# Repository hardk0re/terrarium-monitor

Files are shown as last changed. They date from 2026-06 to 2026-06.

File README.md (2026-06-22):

# 🦎 Terrarium Monitor

A Raspberry Pi-based enclosure monitoring and automation system, built for my daughter's Crested Gecko. Yes, it's total overkill. But it works great.

---

## The Story

I looked at a dozen of these projects online and they were all either too complicated, half-finished, or required cloud accounts and subscriptions. I just wanted something that would:

- Show me temperature and humidity at a glance
- Turn the lights on and off on a schedule
- Kick on the mister if it gets too dry
- Run a fan if it gets too hot
- Let me check in on the enclosure remotely
- Keep a log of feedings and care

So I built it myself. It runs entirely on the local network — no cloud, no subscriptions, no accounts required (except an optional free OpenWeatherMap API key for outdoor weather).

---

## Features

- **Dual SHT31-D sensor monitoring** — temperature and humidity from up to N sensors (expandable via config), with optional per-sensor calibration offsets for chip-to-chip variance
- **ST7789 2" display** — sensor data by default; pre-empts to a gecko-mood page when the gecko isn't happy, and flashes a confirmation screen when a physical button is pressed
- **Day/night display brightness** — PWM-controlled backlight with a separate `night_brightness` and configurable `night_start` / `night_end` window
- **Colour-coded readings** — green = good range, blue = too cold/dry, red = too hot/humid, yellow = sensor error
- **Misting control** — 5V relay triggers automatically when humidity drops below threshold, with configurable runtime, cooldown delay, and 24-hour run cap
- **Fan control** — separate 5V relay for high/low temperature, same configurable runtime and cooldown system; threshold unit (`F`/`C`) follows the display unit or can be set per section
- **TAPO/KASA smart plug lighting** — local API control, no cloud required, fully scheduled (on/off time per plug); shutdown leaves plugs in whatever state they were in
- **TAPO camera** — ONVIF snapshot every 30 seconds, live image in web dashboard, optional timelapse viewer with scrub bar + playback controls and configurable retention
- **Outdoor weather** — OpenWeatherMap integration with current conditions card, 24h history chart, and feels-like / wind
- **Gecko mood widget** — color-changing gecko (green/yellow/red) on the dashboard derived from temperature, humidity, and check-in recency; tunable thresholds in `[gecko]`. Mood transitions are logged and Pushover-notified.
- **Pushover notifications** — per-category toggles (startup/shutdown/care/feeding/relay/error/etc.), louder sounds for errors and upset-gecko transitions, plus a one-click **Test Pushover** button on the config page
- **Care / feeding check-in reminder** — dashboard banner + Pushover when no care or feeding log has been recorded in `care_reminder_hours`
- **Sensor failure alerts** — if a sensor goes silent for `sensor_failure_alert_minutes`, an `error` event is raised (and Pushover-notified)
- **24h sensor averages widget** — average temp + half-moon humidity gauge per sensor, colour-banded with the same thresholds as the OLED
- **System stats widget** — CPU temperature, CPU %, RAM %, free disk, and uptime, with colour thresholds
- **Web dashboard** — live sensor data, charts, relay overrides, light controls, camera snapshot, feeding/care log, config editor
- **Event log viewer** — `/logs` page with category pills (care, feeding, gecko, relay, error, …), time-range filter, and full-text search
- **Feeding log** — one-tap buttons for configurable food items (crickets, waxworms, paste, etc.)
- **Care log** — one-tap buttons for configurable care activities (cleaning, misting, substrate change, vet visit, etc.)
- **Physical buttons** — up to three optional momentary push-buttons wired to GPIO pins, each with its own configurable log category (`care`, `feeding`, etc.) and message — handy when your hands are wet from misting and the web UI isn't convenient (one press → one log entry → display flash → Pushover if that category is enabled)
- **SQLite logging** — all sensor readings, weather, relay events, and care/feeding entries stored locally with configurable retention (default 31 days); web buttons to clear sensor data or the event log
- **Config editor** — edit any config value from the web UI without touching the Pi, plus a **Restart** button that asks systemd to bounce the service
- **Config reload** — most changes apply immediately without a restart
- **Systemd service** — auto-starts on boot, restarts on crash

---

## Hardware

| Component | Notes |
|---|---|
| Raspberry Pi 3B+ or better | CM4 with eMMC recommended for permanent installs |
| Waveshare 2" ST7789 IPS LCD | 240×320, SPI interface |
| SHT31-D sensor module(s) | I²C, supports multiple (0x44 / 0x45) |
| 5V relay module(s) | Active-LOW, for mister and fan |
| TP-Link Tapo smart plugs | P100/P105/P110, local API, no auth required |
| TP-Link Tapo camera | ONVIF enabled, local network |
| MicroSD card | High-endurance recommended (Samsung or SanDisk) |

---

## Wiring
Usefull RPI3 Pin-Out:


### SHT31-D Sensors (I²C)
```
Sensor 1 (0x44) → ADDR pin to GND or OPEN
Sensor 2 (0x45) → ADDR pin to 3.3V

Both sensors:
  VCC → Pin 1  (3.3V)
  GND → Pin 6  (GND)
  SDA → Pin 3  (GPIO2)
  SCL → Pin 5  (GPIO3)
```

### Relay – Mister (HOME ASSISTANT)
Intial plans for the mister was to use a 5V relay, however with so many WIFI enabled misters on ALIExpress, Home Assistant integration was simpler.  I could not get TUYA integration to work reliably.  If your running this your likely using HOMEASSISTANT, if not you should consider it. 

### Relay – Fan (GPIO 27)
```
IN  → Pin 13 (GPIO27)
VCC → Pin 4  (5V)
GND → Pin 14 (GND)
```

### Care/Feeding Buttons (up to 3, optional)
Momentary push-buttons. The internal pull-up keeps each line HIGH; pressing
shorts it to GND. No external resistors needed. Each button is independent —
enable only the ones you've wired in `config.ini` under `[care_button_1]`,
`[care_button_2]`, `[care_button_3]`.

These default pins are deliberately on the bottom-right corner of the header
so they don't collide with the display (which uses GPIO 24/25) and share a
single nearby GND:

```
Button 1: GPIO13  (Pin 33) ─┐
Button 2: GPIO19  (Pin 35) ─┼──── other leg → GND on Pin 39
Button 3: GPIO26  (Pin 37) ─┘
```

Each button section sets its own `category` (e.g. `care`, `feeding`) and
`message` (e.g. `Cleaning`, `Cricket`) — when pressed, that text is logged
under that category, shows up in the event log, and fires a Pushover
notification if `notify_<category>` is enabled in `[pushover]`.

### Waveshare 2" ST7789 Display
```
VCC → Pin 17 (3.3V)
GND → Pin 20 (GND)
DIN → Pin 19 (GPIO10 / MOSI)
CLK → Pin 23 (GPIO11 / SCLK)
CS  → Pin 24 (GPIO8  / CE0)
DC  → Pin 18 (GPIO24)
RST → Pin 22 (GPIO25)
BL  → Pin 12 (GPIO18 / PWM0)
```

---

## Software Setup

### 1. Enable interfaces
```bash
sudo raspi-config
# Interface Options → I2C → Enable
# Interface Options → SPI → Enable
sudo reboot
```

### 2. Copy project files
```bash
mkdir -p /home/pi/terrarium
cd /home/pi/terrarium
# copy all project files here
mkdir -p data
```

### 3. Create virtual environment and install dependencies
```bash
python3 -m venv venv
source venv/bin/activate

pip install \
  adafruit-blinka \
  adafruit-circuitpython-sht31d \
  RPi.GPIO \
  spidev \
  Pillow \
  flask \
  PyP100 \
  requests \
  opencv-python-headless
```

### 4. Configure
```bash
cp sample_config.ini config.ini
vi config.ini
```

Key things to set:
- `[tapo_plug_1]` / `[tapo_plug_2]` → IP addresses of your smart plugs
- `[camera]` → IP, ONVIF port, username, password
- `[weather]` → your OpenWeatherMap API key, latitude, longitude
- `[display]` → `temp_unit = F` or `C`
- `[mister]` / `[fan]` → thresholds and runtimes for your setup
- `[web]` → `site_title`, auth settings

### 5. Test run
```bash
source venv/bin/activate
python main.py
```

Open `http://<pi-ip>:8080` in your browser.

### 6. Install as a systemd service
```bash
sudo cp terrarium.service /etc/systemd/system/
sudo systemctl daemon-reload
sudo systemctl enable terrarium
sudo systemctl start terrarium

# Check logs
sudo journalctl -u terrarium -f
```

---

## File Structure

```
terrarium/
├── config.ini                  ← all settings
├── main.py                     ← entry point
├── sensor_manager.py           ← SHT31 sensor reading
├── data_logger.py              ← SQLite storage
├── relay_controller.py         ← GPIO relay control
├── tapo_controller.py          ← smart plug control
├── display_manager.py          ← ST7789 display driver
├── camera_manager.py           ← TAPO ONVIF camera
├── weather_manager.py          ← OpenWeatherMap
├── web_dashboard.py            ← Flask web UI
├── care_button.py              ← GPIO push-buttons (up to 3) → log entries
├── gecko_mood.py               ← shared mood scoring (dashboard + OLED)
├── pushover_notifier.py        ← Pushover push notifications
├── terrarium.service           ← systemd unit
└── stls/
    ├── LCD-CASE.stl            ← Front of LCD Case
    ├── LCD-REARCOVER.stl       ← Rear Cover
    ├── LCD-RETENTION.stl       ← Retention bar for LCD
    ├── LCD-ButtonRetention.stl ← Retention plates for standard project buttons
    ├── SHT31_BOTTOM.stl        ← SHT31 Case - Bottom
    ├── SHT31_TOP.stl           ← SHT31 Case - Top
└── data/
    ├── terrarium.db        ← SQLite database (auto-created)
    ├── terrarium.log       ← log file (auto-created)
    ├── snapshot.jpg        ← latest camera snapshot
    └── timelapse/          ← timelapse frames (if enabled)
```

---

## Web Dashboard

| URL | Description |
|-----|---|
| `http://<pi-ip>:8080/` | Live dashboard |
| `http://<pi-ip>:8080/logs` | Filterable event log viewer |
| `http://<pi-ip>:8080/timelapse` | Timelapse viewer with playback / scrubber |
| `http://<pi-ip>:8080/config` | Config editor (password protected) |
| `http://<pi-ip>:8080/api/status` | JSON status snapshot |
| `http://<pi-ip>:8080/api/history?hours=24` | Sensor history |
| `http://<pi-ip>:8080/api/sensors/averages?hours=24` | Per-sensor 24h averages |
| `http://<pi-ip>:8080/api/weather/history` | Weather history |
| `http://<pi-ip>:8080/api/gecko/status` | Current gecko mood + per-factor reasons |
| `http://<pi-ip>:8080/api/care/status` | Whether a care/feeding check-in is overdue |
| `http://<pi-ip>:8080/api/system/stats` | CPU temp / CPU % / RAM / free disk / uptime |
| `http://<pi-ip>:8080/api/logs?hours=24&categories=care,feeding&q=cricket` | Filtered event log |
| `POST /api/relay/Mister/on` | Force mister on |
| `POST /api/relay/Fan/off` | Force fan off |
| `POST /api/light/UVB%20Light/on` | Force plug on |
| `POST /api/pushover/test` | Send a test Pushover notification |
| `POST /api/sensors/clear` | Wipe all indoor sensor history |
| `POST /api/log/clear` | Wipe the event + relay log |

---

## Control Logic

```
Every poll_interval_seconds (default 30s):

  MISTER:
    if avg_humidity < humidity_threshold_low
    AND not running AND not in cooldown
    AND 24h run count < mister_max_runs_per_24h:
      → ON for mister_runtime_minutes
      → cooldown for mister_monitor_delay_minutes
      → re-evaluate

  FAN:
    if avg_temp > temp_threshold_high  (too hot)
    OR avg_temp < temp_threshold_low   (too cold)
    AND not running AND not in cooldown
    AND 24h run count < fan_max_runs_per_24h:
      → ON for fan_runtime_minutes
      → cooldown for fan_monitor_delay_minutes
      → re-evaluate

  LIGHTS:
    Background thread checks every 60s:
    if current time between on_time and off_time → ON
    else → OFF
```

---

## Adding More Sensors

Add a new `[sensor_N]` section to `config.ini` — no code changes needed:

```ini
[sensor_3]
enabled = true
name = Basking Spot
i2c_address = 0x44
i2c_bus = 3
```

> **Note:** Only two I²C addresses are available on a single bus (0x44 and 0x45). For more than two sensors on the same bus, use a TCA9548A I²C multiplexer.

## Security

> ⚠️ **Do not expose this dashboard directly to the public internet.** It's
> designed for use on a trusted LAN only. The dashboard is wide open by
> default, multiple destructive endpoints (`/api/relay/*`, `/api/shutdown`,
> `/api/sensors/clear`, `/api/log/clear`, the config editor) require no auth
> unless you flip `auth_enabled = true`, and there's no CSRF protection or
> HTTPS in front of Flask.

**Use it on your home LAN.** That's the whole threat model the project was
built for. Family members poking buttons is fine — exposing port 8080 on
your router is not.

**If you genuinely need to reach it while away from home**, use a VPN

**Even on your LAN**, a few cheap hardening steps are worth doing:

1. Set `auth_enabled = true` in `[web]` and change the default `password = terrarium`.
2. Change `app.secret_key` in `web_dashboard.py` to a random value
   (`python3 -c "import secrets; print(secrets.token_hex(32))"`). Without
   this, anyone who has seen the public repo can forge a logged-in session
   cookie.
3. Treat **anything you've ever put in `config.ini` while it was in a public
   git repo as compromised** — rotate camera, Pushover, OpenWeather, and any
   smart-plug credentials that have been pushed publicly.
4. Add a `.gitignore` for `config.ini` and `data/` so secrets and your
   sensor history don't end up in commits going forward.

## Notes

- The TAPO camera requires ONVIF to be enabled in the Tapo app under **Advanced Settings → ONVIF**
- Smart plugs on newer firmware may reject unauthenticated local control by default. In the Kasa app, open each device → **Advanced Settings → Third-party compatibility** (sometimes called *Allow third party control*) and enable it. With that toggle on, `PyP100`'s empty-credential path works again on the LAN.
- The web config editor saves immediately but some changes (GPIO pins, I²C addresses, web port) require a restart to take effect
- All data is stored locally in SQLite — nothing leaves your network
- Timelapse frames accumulate quickly; set `timelapse_retention_days` and `timelapse_interval_seconds` appropriately

## Restrospec
- I am not using features I thought I needed (currently).  Such as Mister or Fan, as a result I have disconnected the relay's as they were not required.  Leaving it here as it is an option.
- I am not entirely happy with the LCD enclosure, and sensor enclosures.  But they work.  I used Crazy Glue to hold parts in place such as buttons and the sensor top/bottom.
- External weather is something I thought interesting to log, not sure yet how much I will value this data.
- Originally all my sensors , LCD are connected with project pins/wires.  I found that USB-C connectors are cheap, support up to 16 pins, so I am going to build a new setup with USB-C connectors (confusing for some but this way if you need longer cables...just buy a new USB-C cable)

---

*Built with way too much enthusiasm for a gecko that probably doesn't care.*

LCD Screen:



Main Website:




Configuration Editor:


TimeLapse:


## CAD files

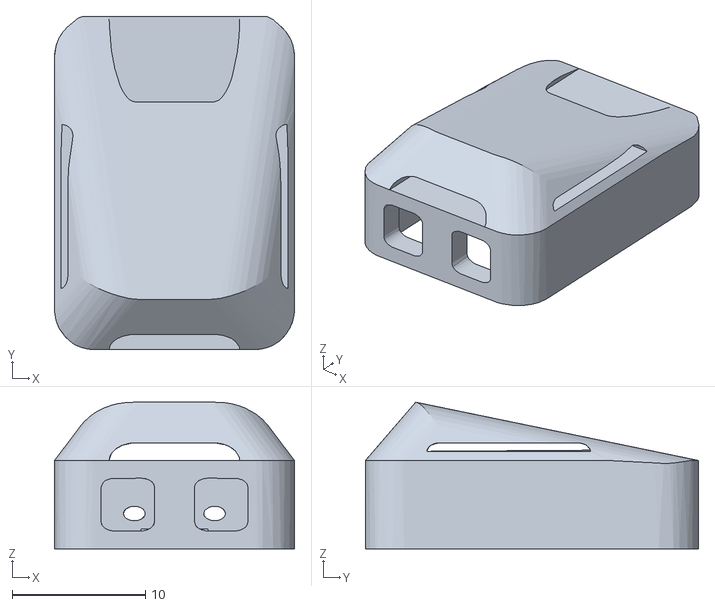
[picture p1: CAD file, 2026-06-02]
STLS/SHT31_TOP.stl
18.0 x 25.0 x 11.0

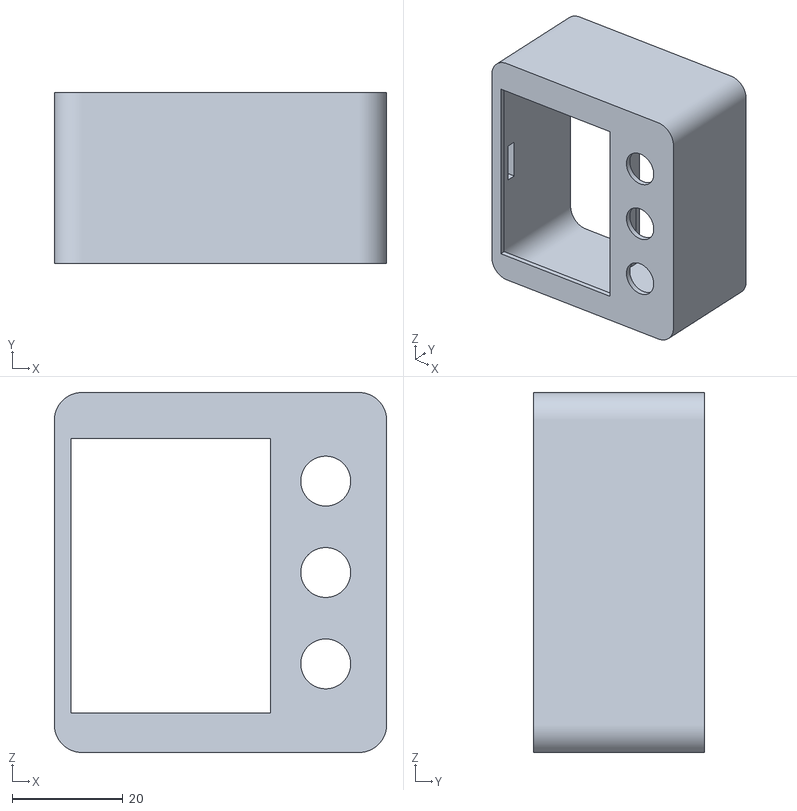
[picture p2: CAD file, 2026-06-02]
STLS/LCD-CASE.stl
60.0 x 30.8 x 65.0

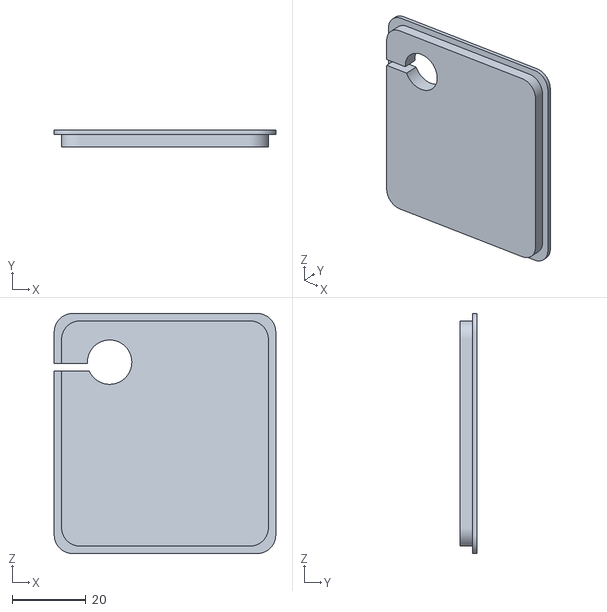
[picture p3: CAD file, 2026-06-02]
STLS/LCD-RETENTION.stl
60.0 x 4.60 x 65.0

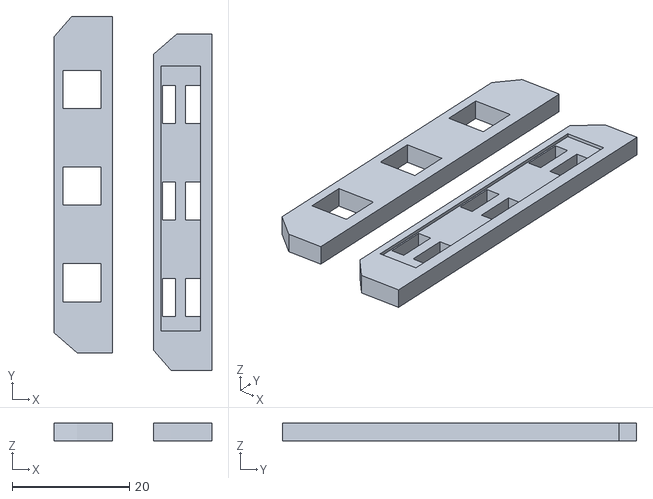
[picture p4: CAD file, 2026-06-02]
STLS/LCD-ButtonRetention.stl
27.0 x 60.5 x 3.00

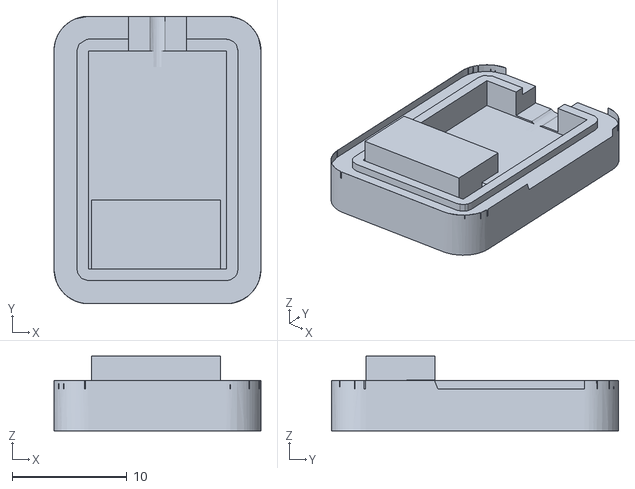
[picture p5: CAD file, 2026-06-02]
STLS/SHT31_BOTTOM.stl
18.0 x 25.0 x 6.50

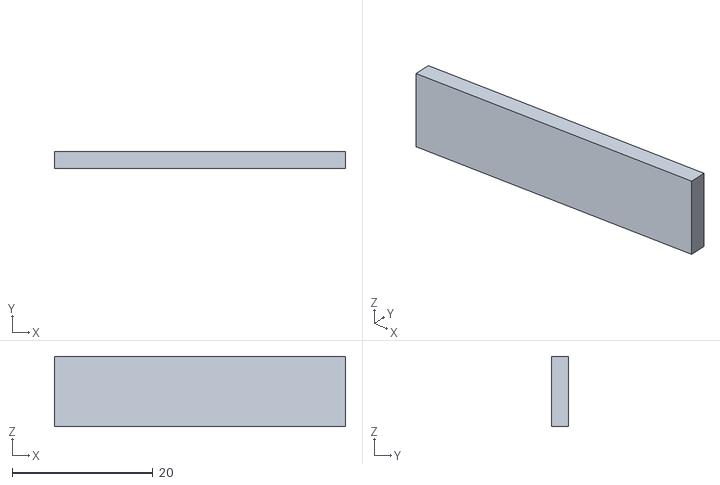
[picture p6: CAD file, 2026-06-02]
STLS/LCD-REARCOVER.stl
41.4 x 2.37 x 10.0

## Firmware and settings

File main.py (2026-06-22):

"""
main.py  –  Terrarium Monitor entry point
Run with:  python main.py
Or via systemd service (see terrarium.service)
"""

import time
import signal
import logging
import configparser
import threading
from pathlib import Path

# ── project modules ───────────────────────────────────────────────────
from sensor_manager   import SensorManager
from data_logger      import DataLogger
from relay_controller import build_mister, build_fan, cleanup_gpio
from homeassistant    import HomeAssistantClient
from tapo_controller  import LightingController
from display_manager  import DisplayManager
from camera_manager   import CameraManager
from weather_manager  import WeatherManager
from pushover_notifier import PushoverNotifier
from care_button       import CareButton
from gecko_mood        import compute_mood
import web_dashboard

# ── logging setup ─────────────────────────────────────────────────────
logging.basicConfig(
    level=logging.INFO,
    format="%(asctime)s [%(levelname)s] %(name)s: %(message)s",
    handlers=[
        logging.StreamHandler(),
        logging.FileHandler(Path(__file__).parent / "data" / "terrarium.log"),
    ]
)
logger = logging.getLogger("main")

# ── config ────────────────────────────────────────────────────────────
CONFIG_PATH = Path(__file__).parent / "config.ini"


def load_config() -> configparser.ConfigParser:
    cfg = configparser.ConfigParser()
    cfg.read(CONFIG_PATH)
    return cfg


# ── subsystem helpers ─────────────────────────────────────────────────

def build_subsystems(cfg: configparser.ConfigParser) -> dict:
    """Instantiate all controllable subsystems from config."""
    ha = HomeAssistantClient(
        cfg.get("general", "ha_base_url", fallback=""),
        cfg.get("general", "ha_token",    fallback=""),
    )
    dl       = DataLogger(cfg)
    sensors  = SensorManager(cfg)
    mister   = build_mister(cfg, dl, ha_client=ha)
    fan      = build_fan(cfg, dl)
    lighting = LightingController(cfg, data_logger=dl)
    camera   = CameraManager(cfg)
    weather  = WeatherManager(cfg, data_logger=dl)
    return dict(dl=dl, ha=ha, sensors=sensors, mister=mister,
                fan=fan, lighting=lighting, camera=camera, weather=weather)


def reload_subsystems(current: dict, cfg: configparser.ConfigParser) -> dict:
    """Gracefully stop current subsystems and rebuild from updated config."""
    logger.info("Reloading subsystems from updated config...")

    # Preserve last weather reading so display doesn't go blank
    last_weather = None
    if current.get("weather") and current["weather"].enabled:
        last_weather = current["weather"].latest()

    try:
        current["lighting"].stop()
        current["camera"].stop()
        current["weather"].stop()
        if current["mister"]: current["mister"].force_off()
        if current["fan"]:    current["fan"].force_off()
    except Exception as e:
        logger.warning("Error stopping subsystems during reload: %s", e)

    new = build_subsystems(cfg)
    new["lighting"].start_schedule_loop()
    new["camera"].start()
    new["weather"].start()

    # Restore last reading so display keeps showing weather immediately
    if last_weather and new["weather"].enabled:
        with new["weather"]._lock:
            new["weather"]._latest = last_weather

    return new


# ── logging helpers ───────────────────────────────────────────────────

def _apply_log_level(cfg: configparser.ConfigParser):
    """Read [general].log_level and apply it to the root logger.
    Werkzeug stays at INFO no matter what — its DEBUG mode is mostly
    HTTP-handshake noise that isn't useful when chasing a terrarium issue."""
    level_str = cfg.get("general", "log_level", fallback="INFO").strip().upper()
    level = getattr(logging, level_str, None)
    if not isinstance(level, int):
        logger.warning("Unknown log_level %r, falling back to INFO.", level_str)
        level = logging.INFO
    logging.getLogger().setLevel(level)
    logging.getLogger("werkzeug").setLevel(logging.INFO)
    if level == logging.DEBUG:
        logger.info("Debug logging enabled (log file will grow faster).")
    else:
        logger.info("Log level: %s.", logging.getLevelName(level))


# ── entry point ───────────────────────────────────────────────────────

def main():
    cfg  = load_config()
    _apply_log_level(cfg)
    subs = build_subsystems(cfg)
    dl, sensors, mister, fan, lighting, camera, weather = (
        subs["dl"], subs["sensors"], subs["mister"],
        subs["fan"], subs["lighting"], subs["camera"], subs["weather"]
    )
    display = DisplayManager(cfg, sensors, mister, fan, lighting, weather,
                             data_logger=dl)

    # ── Pushover notifications ────────────────────────────────────────
    notifier = PushoverNotifier(cfg)
    dl.set_notifier(notifier)
    last_mood = None  # tracks gecko mood transitions across polls

    # ── Physical buttons (up to 3) ────────────────────────────────────
    care_buttons = []
    seen_pins    = set()
    for sec in ("care_button_1", "care_button_2", "care_button_3"):
        if not cfg.has_section(sec):
            continue
        b = CareButton(cfg, dl, sec, display=display, mister=mister)
        if b.pin is not None and b.pin not in seen_pins:
            care_buttons.append(b)
            seen_pins.add(b.pin)
        elif b.pin is not None:
            logger.warning("%s: GPIO %d already in use, skipping.", sec, b.pin)

    # ── Sensor failure tracking ───────────────────────────────────────
    # Per-sensor last successful read time; sensors currently in "failed"
    # state so we only notify on transitions (not every poll).
    from datetime import datetime as _dt
    sensor_last_good = {t[0]: _dt.utcnow() for t in sensors.sensors}
    sensor_failed = set()

    # ── Reload / shutdown events ──────────────────────────────────────
    _stop   = threading.Event()
    _reload = threading.Event()

    def _do_reload():
        _reload.set()

    def _shutdown(sig, frame):
        logger.info("Shutdown signal received.")
        _stop.set()

    signal.signal(signal.SIGINT,  _shutdown)
    signal.signal(signal.SIGTERM, _shutdown)

    # ── Wire web dashboard ────────────────────────────────────────────
    web_dashboard.init(cfg, dl, sensors, mister, fan, lighting, camera, weather,
                       notifier=notifier)
    web_dashboard.set_reload_callback(_do_reload)

    # ── Start background services ─────────────────────────────────────
    lighting.start_schedule_loop()
    camera.start()
    weather.start()
    display.start()

    if cfg.getboolean("web", "enabled", fallback=True):
        threading.Thread(
            target=web_dashboard.run, args=(cfg,),
            daemon=True, name="web"
        ).start()

    poll_sec = cfg.getint("general", "poll_interval_seconds", fallback=30)
    logger.info("Terrarium monitor running. Poll every %ds.", poll_sec)
    dl.log_system_event("startup", f"Terrarium monitor started. Poll interval: {poll_sec}s")

    # ── Main control loop ─────────────────────────────────────────────
    try:
        while not _stop.is_set():

            # Config reload requested by web UI
            if _reload.is_set():
                _reload.clear()
                cfg.read(CONFIG_PATH)
                _apply_log_level(cfg)
                subs = reload_subsystems(subs, cfg)
                dl, sensors, mister, fan, lighting, camera, weather = (
                    subs["dl"], subs["sensors"], subs["mister"],
                    subs["fan"], subs["lighting"], subs["camera"], subs["weather"]
                )
                display.update_components(sensors, mister, fan, lighting, weather,
                                          data_logger=dl)
                notifier.reload(cfg)
                dl.set_notifier(notifier)
                web_dashboard.init(cfg, dl, sensors, mister, fan, lighting, camera, weather,
                                   notifier=notifier)
                web_dashboard.set_reload_callback(_do_reload)
                poll_sec = cfg.getint("general", "poll_interval_seconds", fallback=30)
                logger.info("Subsystems reloaded successfully.")
                dl.log_system_event("config", "Configuration reloaded via web UI")

            # Sensor read + control logic
            readings = sensors.read_all()

            # Sensor failure detection — compare configured-and-initialised
            # sensors vs. who actually reported this cycle. Notify on transitions.
            try:
                threshold_min = cfg.getfloat("general", "sensor_failure_alert_minutes",
                                             fallback=10.0)
                if threshold_min > 0:
                    now_utc = _dt.utcnow()
                    enabled_names = {t[0] for t in sensors.sensors}
                    got_names     = {r.name for r in readings}
                    # Track any newly-added sensors (e.g. after a reload)
                    for n in enabled_names:
                        sensor_last_good.setdefault(n, now_utc)
                    # Drop tracking for sensors no longer enabled
                    for n in list(sensor_last_good):
                        if n not in enabled_names:
                            sensor_last_good.pop(n, None)
                            sensor_failed.discard(n)
                    # Compare each enabled sensor
                    for n in enabled_names:
                        if n in got_names:
                            sensor_last_good[n] = now_utc
                            if n in sensor_failed:
                                sensor_failed.discard(n)
                                dl.log_system_event("error",
                                    f"Sensor '{n}' recovered.")
                        else:
                            minutes_silent = (now_utc - sensor_last_good[n]).total_seconds() / 60
                            if n not in sensor_failed and minutes_silent >= threshold_min:
                                sensor_failed.add(n)
                                dl.log_system_event("error",
                                    f"Sensor '{n}' unresponsive for "
                                    f"{int(minutes_silent)} min.")
            except Exception as e:
                logger.warning("Sensor failure check failed: %s", e)

            if readings:
                dl.log_readings(readings)
                dl.purge_old_data()
                display.update_readings(readings)
                lighting.update_readings(readings)

            # Gecko mood transitions → Pushover. Runs even when sensors fail,
            # because mood is also driven by check-in age (care/feeding logs).
            # notify_mood_change handles its own enabled/configured checks.
            try:
                mood_info = compute_mood(cfg, dl)
                new_mood  = mood_info.get("mood")
                summary   = mood_info.get("summary", "")
                if new_mood and new_mood != "unknown":
                    fire = False
                    if last_mood is None:
                        # First observed mood after startup: only alert if it's
                        # already a problem state worth flagging.
                        fire = (new_mood != "happy")
                        prev_label = "(startup)"
                    elif new_mood != last_mood:
                        fire = True
                        prev_label = last_mood
                    if fire:
                        notifier.notify_mood_change(prev_label, new_mood, summary)
                        msg = f"Mood: {prev_label} → {new_mood}"
                        if summary:
                            msg += f" ({summary})"
                        # Log to the event log table so it shows in the /logs viewer.
                        # Note: this also runs through notify_event for category
                        # "gecko" — but notify_gecko isn't a configured flag so
                        # it stays silent and we don't double-notify.
                        dl.log_system_event("gecko", msg)
                        logger.info("Gecko mood: %s → %s (%s)",
                                    prev_label, new_mood, summary)
                    last_mood = new_mood
            except Exception as e:
                logger.warning("Mood check failed: %s", e)

            # Mister — auto-trigger only when [mister].enabled = true (the
            # mister object still exists when button_enabled = true alone, but
            # we don't fire it from the polling loop in that case).
            if mister and getattr(mister, "auto_enabled", True):
                m_sensor = cfg.get("mister", "sensor", fallback="").strip()
                m_hum    = sensors.humidity_for(readings, m_sensor)
                if m_hum is not None:
                    threshold = cfg.getfloat("mister", "humidity_threshold_low", fallback=50.0)
                    if m_hum < threshold and not mister.is_on and not mister.in_cooldown:
                        src = m_sensor or "avg"
                        logger.info("Humidity %.1f%% (%s) < %.1f%% – triggering mister.",
                                    m_hum, src, threshold)
                        mister.trigger(
                            reason=f"humidity {m_hum:.1f}% (from {src}) < {threshold}%"
                        )

            # Fan — pick its sensor (blank = average of all enabled sensors).
            # Same sensor drives both the temp and humidity checks below.
            if fan:
                f_sensor = cfg.get("fan", "sensor", fallback="").strip()
                f_temp_c = sensors.temperature_for(readings, f_sensor)
                f_hum    = sensors.humidity_for(readings, f_sensor)
                if f_temp_c is not None:
                    src = f_sensor or "avg"
                    # Unit the fan thresholds are written in. [fan].temp_unit
                    # overrides, else fall back to [display].temp_unit.
                    fan_unit = cfg.get("fan", "temp_unit", fallback="").strip().upper()
                    if fan_unit not in ("F", "C"):
                        fan_unit = cfg.get("display", "temp_unit", fallback="F").upper()
                    f_t = f_temp_c * 9 / 5 + 32 if fan_unit == "F" else f_temp_c
                    unit_lbl = "°F" if fan_unit == "F" else "°C"
                    # Defaults track the unit: ~85/65 °F vs 30/18 °C.
                    t_high = cfg.getfloat("fan", "temp_threshold_high",
                                          fallback=85.0 if fan_unit == "F" else 30.0)
                    t_low  = cfg.getfloat("fan", "temp_threshold_low",
                                          fallback=65.0 if fan_unit == "F" else 18.0)
                    h_high = cfg.getfloat("fan", "humidity_threshold_high", fallback=80.0)
                    runtime_min = cfg.getfloat("fan", "fan_runtime_minutes", fallback=10.0)

                    # Three independent trigger conditions
                    too_hot   = f_t > t_high
                    too_cold  = f_t < t_low
                    too_humid = f_hum is not None and f_hum > h_high
                    wants_on  = too_hot or too_cold or too_humid

                    if wants_on:
                        reasons = []
                        if too_hot:   reasons.append(f"temp {f_t:.1f}{unit_lbl} ({src}) > {t_high}{unit_lbl}")
                        if too_cold:  reasons.append(f"temp {f_t:.1f}{unit_lbl} ({src}) < {t_low}{unit_lbl}")
                        if too_humid: reasons.append(f"humidity {f_hum:.1f}% ({src}) > {h_high}%")
                        reason_str = "; ".join(reasons)

                    if runtime_min <= 0:
                        # Continuous mode — match relay state to conditions every poll.
                        if wants_on and not fan.is_on:
                            logger.info("Fan ON (continuous) – %s", reason_str)
                            fan.trigger(reason=reason_str)
                        elif not wants_on and fan.is_on:
                            logger.info("Fan OFF (continuous) – conditions cleared.")
                            fan.force_off()
                    else:
                        # Timed mode — kick off a fixed-length cycle, then cooldown.
                        if wants_on and not fan.is_on and not fan.in_cooldown:
                            logger.info("Fan ON (timed %.1f min) – %s",
                                        runtime_min, reason_str)
                            fan.trigger(reason=reason_str)

            # Sleep in small chunks so stop/reload events respond quickly
            for _ in range(poll_sec * 2):
                if _stop.is_set() or _reload.is_set():
                    break
                time.sleep(0.5)

    except KeyboardInterrupt:
        pass
    finally:
        logger.info("Cleaning up...")
        dl.log_system_event("shutdown", "Terrarium monitor shutting down")
        display.stop()
        camera.stop()
        weather.stop()
        # Stop the schedule loop but leave the Tapo plugs in whatever state
        # they were in — we shouldn't yank UVB / basking lights when restarting.
        lighting.stop()
        for b in care_buttons:
            b.stop()
        if mister: mister.force_off()
        if fan:    fan.force_off()
        cleanup_gpio()
        logger.info("Shutdown complete.")


if __name__ == "__main__":
    main()

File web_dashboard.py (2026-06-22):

"""
web_dashboard.py
Flask web dashboard with live status, history charts, manual overrides,
and a full config editor page (auth-protected if enabled).
"""

import logging
import configparser
from datetime import datetime, timezone, timedelta
from pathlib import Path
from functools import wraps
from flask import Flask, jsonify, request, Response, redirect, url_for, session

logger = logging.getLogger(__name__)
app = Flask(__name__)
# generate a new Key: python3 -c "import secrets; print(secrets.token_hex(32))"
app.secret_key = "a48af364f1b148da855cb51057ecfa179bc7c572b439dee84bf0f49fa6fcfe60"

CONFIG_PATH = Path(__file__).parent / "config.ini"

def _utc_to_local(ts: str) -> str:
    """Convert UTC ISO timestamp to local time using utc_offset_hours from config."""
    try:
        offset_hours = _config.getfloat("general", "utc_offset_hours", fallback=0) if _config else 0
        dt = datetime.fromisoformat(ts).replace(tzinfo=timezone.utc)
        local = dt + timedelta(hours=offset_hours)
        return local.strftime("%Y-%m-%d %H:%M")
    except Exception:
        return ts.replace("T", " ")[:16]

# Injected by main.py
_data_logger     = None
_sensor_mgr      = None
_mister          = None
_fan             = None
_lighting        = None
_camera          = None
_weather         = None
_notifier        = None
_config          = None
_reload_callback = None


def set_reload_callback(fn):
    global _reload_callback
    _reload_callback = fn


def init(config, data_logger, sensor_manager, mister, fan, lighting,
         camera=None, weather=None, notifier=None):
    global _data_logger, _sensor_mgr, _mister, _fan, _lighting, _camera, _weather, _notifier, _config
    _data_logger  = data_logger
    _sensor_mgr   = sensor_manager
    _mister       = mister
    _fan          = fan
    _lighting     = lighting
    _camera       = camera
    _weather      = weather
    _notifier     = notifier
    _config       = config


# ------------------------------------------------------------------
# Auth helpers
# ------------------------------------------------------------------

def _auth_enabled():
    return _config and _config.getboolean("web", "auth_enabled", fallback=False)

def _config_protected():
    return _config and _config.getboolean("web", "config_protected", fallback=True)

def _check_credentials(username, password):
    return (username == _config.get("web", "username", fallback="admin") and
            password == _config.get("web", "password", fallback="terrarium"))

def _check_config_credentials(username, password):
    return (username == _config.get("web", "config_username", fallback="admin") and
            password == _config.get("web", "config_password", fallback="terrarium"))

def _auth_required(f):
    @wraps(f)
    def decorated(*args, **kwargs):
        if not _auth_enabled():
            return f(*args, **kwargs)
        if session.get("logged_in"):
            return f(*args, **kwargs)
        auth = request.authorization
        if auth and _check_credentials(auth.username, auth.password):
            return f(*args, **kwargs)
        if request.accept_mimetypes.accept_html:
            return redirect(url_for("login", next=request.path))
        return Response("Unauthorised", 401,
                        {"WWW-Authenticate": 'Basic realm="Terrarium"'})
    return decorated


def _config_auth_required(f):
    @wraps(f)
    def decorated(*args, **kwargs):
        # If full auth is on and user is already logged in, allow through
        if _auth_enabled() and session.get("logged_in"):
            return f(*args, **kwargs)
        # Check config-specific session flag
        if session.get("config_logged_in"):
            return f(*args, **kwargs)
        # If config_protected is off, allow through
        if not _config_protected():
            return f(*args, **kwargs)
        # Check HTTP Basic for API access
        auth = request.authorization
        if auth and _check_config_credentials(auth.username, auth.password):
            return f(*args, **kwargs)
        # Redirect browser to config login
        if request.accept_mimetypes.accept_html:
            return redirect(url_for("config_login", next=request.path))
        return Response("Unauthorised", 401,
                        {"WWW-Authenticate": 'Basic realm="Terrarium Config"'})
    return decorated


# ------------------------------------------------------------------
# Login / Logout
# ------------------------------------------------------------------
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

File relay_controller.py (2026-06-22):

"""
relay_controller.py
Controls GPIO relays for the mister and fan with run-time limits,
monitor delays, and 24-hour run-count caps.
"""

import time
import logging
import threading
import configparser
from datetime import datetime

try:
    import RPi.GPIO as GPIO
    GPIO.setmode(GPIO.BCM)
    GPIO.setwarnings(False)
    _GPIO_AVAILABLE = True
except ImportError:
    _GPIO_AVAILABLE = False
    logging.warning("RPi.GPIO not available – running in simulation mode.")

logger = logging.getLogger(__name__)


class RelayController:
    """
    Manages a single GPIO relay with:
      - configurable ON duration
      - post-run monitor delay before re-evaluating
      - 24-hour run count cap
    """

    def __init__(self, name: str, gpio_pin: int, active_low: bool,
                 runtime_minutes: float, monitor_delay_minutes: float,
                 max_runs_per_24h: int, data_logger=None):
        self.name                = name
        self.gpio_pin            = gpio_pin
        self.active_low          = active_low
        self.runtime_minutes     = runtime_minutes
        self.monitor_delay_min   = monitor_delay_minutes
        self.max_runs_per_24h    = max_runs_per_24h
        self.data_logger         = data_logger

        self._is_on              = False
        self._lock               = threading.Lock()
        self._cooldown_until     = 0.0   # epoch seconds – don't re-trigger before this

        if _GPIO_AVAILABLE:
            GPIO.setup(self.gpio_pin, GPIO.OUT)
            self._write(False)

    # ------------------------------------------------------------------
    # Internal GPIO helpers
    # ------------------------------------------------------------------

    def _write(self, state: bool):
        """Drive the GPIO pin, honouring active_low wiring."""
        if not _GPIO_AVAILABLE:
            logger.info("[SIM] GPIO %d → %s", self.gpio_pin, "ON" if state else "OFF")
            return
        GPIO.output(self.gpio_pin, not state if self.active_low else state)

    # ------------------------------------------------------------------
    # Public API
    # ------------------------------------------------------------------

    @property
    def is_on(self) -> bool:
        return self._is_on

    @property
    def in_cooldown(self) -> bool:
        return time.monotonic() < self._cooldown_until

    def _run_count_24h(self) -> int:
        if self.data_logger:
            return self.data_logger.get_relay_run_count(self.name, hours=24)
        return 0

    def trigger(self, reason: str = "") -> bool:
        """
        Attempt to start a relay cycle.
        - runtime_minutes > 0: timed cycle, then cooldown, capped at max_runs_per_24h.
        - runtime_minutes <= 0: continuous mode — turn on and leave on. The
          caller is responsible for calling force_off() when conditions clear.
          The 24h run cap is skipped in continuous mode since there are no
          discrete "runs" to count.
        Returns True if the relay was turned on, False if blocked.
        """
        continuous = self.runtime_minutes <= 0
        with self._lock:
            if self._is_on:
                logger.debug("%s already running.", self.name)
                return False

            if self.in_cooldown:
                remaining = self._cooldown_until - time.monotonic()
                logger.info("%s in cooldown – %.1f min remaining.", self.name, remaining / 60)
                return False

            if not continuous and self.max_runs_per_24h > 0:
                runs = self._run_count_24h()
                if runs >= self.max_runs_per_24h:
                    logger.warning("%s hit 24h run cap (%d/%d).",
                                   self.name, runs, self.max_runs_per_24h)
                    return False

            self._is_on = True
            self._write(True)
            if self.data_logger:
                self.data_logger.log_relay_event(self.name, "ON", reason)
            mode_label = "continuous" if continuous else f"runtime {self.runtime_minutes:.1f} min"
            logger.info("%s ON – %s | reason: %s", self.name, mode_label, reason)

        if not continuous:
            t = threading.Thread(target=self._auto_off, daemon=True)
            t.start()
        return True

    def force_off(self):
        """Immediately turn the relay off (e.g. on shutdown)."""
        with self._lock:
            self._write(False)
            if self._is_on:
                self._is_on = False
                if self.data_logger:
                    self.data_logger.log_relay_event(self.name, "OFF", "forced off")
                logger.info("%s force OFF.", self.name)

    # ------------------------------------------------------------------
    # Background cycle
    # ------------------------------------------------------------------

    def _auto_off(self):
        """Run for runtime_minutes, then start the monitor delay cooldown."""
        time.sleep(self.runtime_minutes * 60)
        with self._lock:
            self._write(False)
            self._is_on = False
            cooldown_sec = self.monitor_delay_min * 60
            self._cooldown_until = time.monotonic() + cooldown_sec
            if self.data_logger:
                self.data_logger.log_relay_event(self.name, "OFF",
                                                 f"auto off after {self.runtime_minutes} min")
        logger.info("%s OFF – monitor delay %.1f min before re-check.",
                    self.name, self.monitor_delay_min)


# ======================================================================
# HARelay — mimics RelayController's public API but drives a Home Assistant
# entity (switch.*) instead of a GPIO pin. Runtime/cooldown are tracked in
# SECONDS rather than minutes for finer control (misting cycles are short).
# ======================================================================
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

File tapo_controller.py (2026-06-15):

"""
tapo_controller.py
Controls TAPO WiFi smart plugs via local UDP broadcast (no cloud, no auth).
Uses the PyP100 / tplink-smarthome local protocol (port 9999).

Compatible plugs: P100, P105, P110 and similar TP-Link Tapo devices
that support the unauthenticated local UDP command on firmware < 1.2.x,
OR the newer tplink_smarthome_protocol for updated firmware.

Install: pip install PyP100
"""

import logging
import socket
import json
import configparser
from datetime import datetime, time as dtime
from threading import Thread
import time

logger = logging.getLogger(__name__)

# Try PyP100 first, fall back to raw UDP
try:
    from PyP100 import PyP100
    _USE_PYP100 = True
    logger.info("Using PyP100 library for TAPO control.")
except ImportError:
    _USE_PYP100 = False
    logger.warning("PyP100 not found – falling back to raw UDP broadcast.")


# ======================================================================
# Low-level raw UDP helper (no-auth protocol, older firmware)
# ======================================================================

_XOR_KEY = 0xAB

def _xor_encrypt(data: bytes) -> bytes:
    key = _XOR_KEY
    out = []
    for b in data:
        enc = b ^ key
        key = enc
        out.append(enc)
    return bytes(out)

def _build_packet(payload: dict) -> bytes:
    raw = json.dumps(payload).encode()
    encrypted = _xor_encrypt(raw)
    # 4-byte big-endian length header
    return len(encrypted).to_bytes(4, "big") + encrypted

def _raw_send(ip: str, payload: dict, port: int = 9999, timeout: float = 3.0) -> dict | None:
    try:
        pkt = _build_packet(payload)
        with socket.socket(socket.AF_INET, socket.SOCK_STREAM) as s:
            s.settimeout(timeout)
            s.connect((ip, port))
            s.sendall(pkt)
            resp = s.recv(4096)
        if len(resp) < 4:
            return None
        body = resp[4:]           # strip length header
        key = _XOR_KEY
        plain = []
        for b in body:
            plain.append(b ^ key)
            key = b
        return json.loads(bytes(plain).decode())
    except Exception as e:
        logger.error("Raw UDP/TCP error talking to %s: %s", ip, e)
        return None


# ======================================================================
# TapoPlug – single plug abstraction
# ======================================================================

class TapoPlug:
    def __init__(self, name: str, ip: str, on_time: dtime, off_time: dtime,
                 mode: str = "light", data_logger=None):
        self.name       = name
        self.ip         = ip
        self.on_time    = on_time
        self.off_time   = off_time
        # mode: "light" = scheduled on/off; "fan" = on within the window only
        # when avg temp or humidity exceeds thresholds in [fan].
        self.mode       = (mode or "light").lower().strip()
        if self.mode not in ("light", "fan"):
            logger.warning("Unknown plug mode '%s' for %s — defaulting to 'light'.",
                           mode, name)
            self.mode = "light"
        self.data_logger = data_logger
        self._state     = None   # True = on, False = off, None = unknown
        self.last_reason = ""    # set by should_be_on; logged on state change

        if _USE_PYP100:
            try:
                self._device = PyP100.P100(ip, "", "")   # no credentials needed
                self._device.handshake()
            except Exception as e:
                logger.warning("PyP100 handshake failed for %s (%s): %s", name, ip, e)
                self._device = None
        else:
            self._device = None

    # ------------------------------------------------------------------
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

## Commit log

2026-05-28 added sensor failure alerts.
    [main.py, sample_config.ini]
2026-05-28 added physical button for care/checkin.
2026-05-31 added C / F setting for mood and fan setting.
2026-06-01 updated care buttons, 3 of them, gecko mood fixes.
    gecko mood fixes and care button updates (3 buttons).
    [camera_manager.py, care_button.py, display_manager.py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]
2026-06-01 updated dashboard / notes
    updated dashboard to clear sensor data.
    updated readme.md
2026-06-02 Updates
    Sensor Read Updates, Display Updates no longer show outside weather, just required internal temp/humidity and UVB indicator of command on.
    [care_button.py, display_manager.py, main.py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]
2026-06-02 STL Files
    [LCD-ButtonRetention.stl, LCD-CASE.stl, LCD-REARCOVER.stl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]
2026-06-02 Sensor Graph Updates
    - Sensor Time displayed in Graph was wrong.
    - Added smoothing to the graph.
    [web_dashboard.py]
2026-06-03 updated switches to be fans
    added a setting to use a tapo plug as a fan switch, in fact this is becoming my favourite way vs using relays... local api works. Note if you upgrade your firmware allow 3rd party apps...
2026-06-03 1.0.100
    removed low humidity turn off, so fan just turns off when it gets below max humidity, vs running to get below a low threshold.
    added tracking version.py.
    updated tapo controller logic
    web_dashboard updated to display version.
2026-06-03 1.0.102
    added average widget, sensor fixing for fan/mister.
    [main.py, sample_config.ini, sensor_manager.py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]
2026-06-22 1.0.110
    removed gpio for mister, and using home assistant to enable/disable switch or plug for smartlife/tuya mister.
2026-06-22 Enhance README with relay and Home Assistant details
    Updated the README with information about relay integration and Home Assistant.
